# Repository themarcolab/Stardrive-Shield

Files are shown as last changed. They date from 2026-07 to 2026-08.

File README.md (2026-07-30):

# STARDRIVE SHIELD

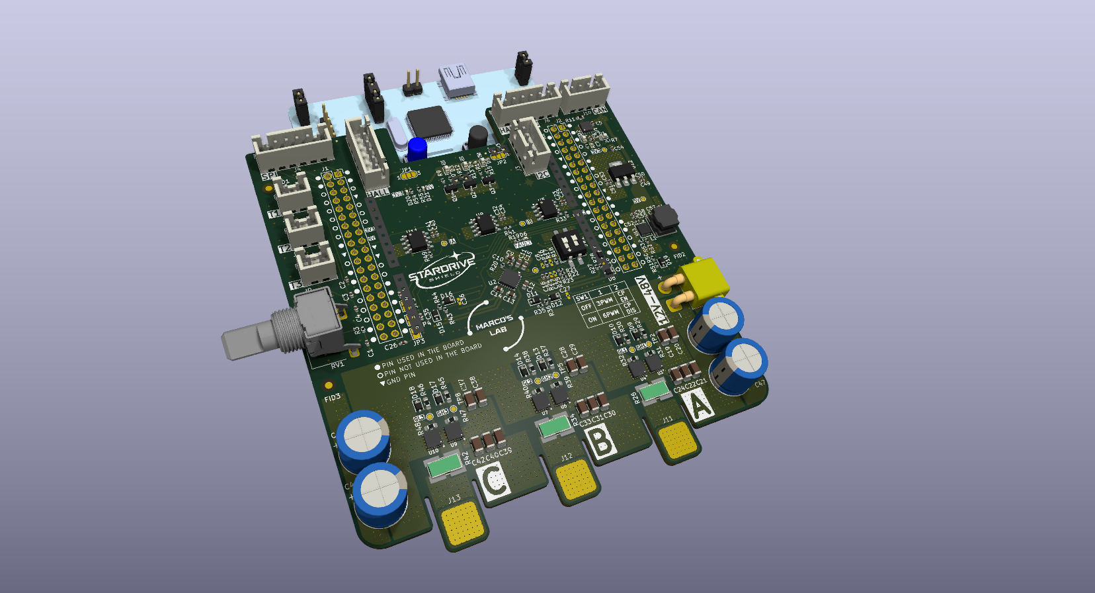
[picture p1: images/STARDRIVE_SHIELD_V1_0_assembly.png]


## Introduction
This project has been born because I have been trying to develop an ESC (hardware and firmware) on my own. 
While the most challenging part has been the firmware (being myself a hardware guy), the most frustrating part has been not finding a flexible hardware platform to develop upon.

So I designed one: **STARDRIVE SHIELD**

## Description 
This is a project with the goal of creating a NUCLEO-64 compatible shield to be used as a flexible platform to develop and test ESC firmware, but also for educational purposes. To do so, I included as many features as possible. These features are not mandatory, but they can be implemented (or not) in the firmware (e.g. SPI, I2C, CAN, HALL) or configured through the hardware interface (e.g. overcurrent protection, 6 or 3 PWM). In this way, the STARDRIVE SHIELD grants flexibility to the developer and it is adapt to various needs.

## Features
The **STARDRIVE SHIELD** is built around the [STDRIVE101](https://www.st.com/en/power-management/stdrive101.html)  gate driver and implementing [BSZ099N06LS5](https://www.infineon.com/part/BSZ099N06LS5) MOSFETs.
It presents 3 in-line shunt resistors and 3 relative [INA240A2](https://www.ti.com/lit/ds/symlink/ina240.pdf?ts=1785176124311&ref_url=https%253A%252F%252Fwww.google.com%252F) current sense amplifiers.

With **STARDRIVE SHIELD** you can implement from 6 step to FOC motor control algorithms.

I designed it to be compatible with Nucleo-G474 and Nucleo-F446. Compatibility with other boards has to be verified. 

### Electrical Characteristics
+ Inprut Voltage V<sub>in</sub> = 12 - 48 V
+ Maximum DC current I<sub>dc,max</sub> = 20 A

### Hardware Characteristiscs
+ Three phase gate driver [STDRIVE101](https://www.st.com/en/power-management/stdrive101.html)
  + Configurable 3PWM or 6PWM through the DIP switch
  + Overcurrent protection can be enabled or disabled through the DIP switch.
  + V<sub>ds</sub> protection configurable with resistor divider (disabled by default)
+ [BSZ099N06LS5](https://www.infineon.com/part/BSZ099N06LS5) MOSFETs
+ 3 in-line shunt resistors (1mOhm) with relative 3 INA240A2 Current Sensors
+ JST connectors to implement:
  + I2C (e.g. for magnetic encoder such as [AS5046](https://mm.digikey.com/Volume0/opasdata/d220001/medias/docus/1138/AS5046.pdf))
  + SPI (e.g. for magnetic encoder such as [AS5047P](https://look.ams-osram.com/m/d05ee39221f9857/original/AS5047P-DS000324.pdf))
  + CAN
  + HALL sensors (some BLDC motors have embedded Hall sensors)
  + 3 NTC temperature sensors
+ 10k Potentiometer to use as throttle signal (or whatever you want)
+ 3 GPIO driven LEDs (1 Red, 1 Blue, 1 Green)
+ 1 FAULT LED (RED)
+ CAN RX and TX LEDs
+ Power Good LEDs

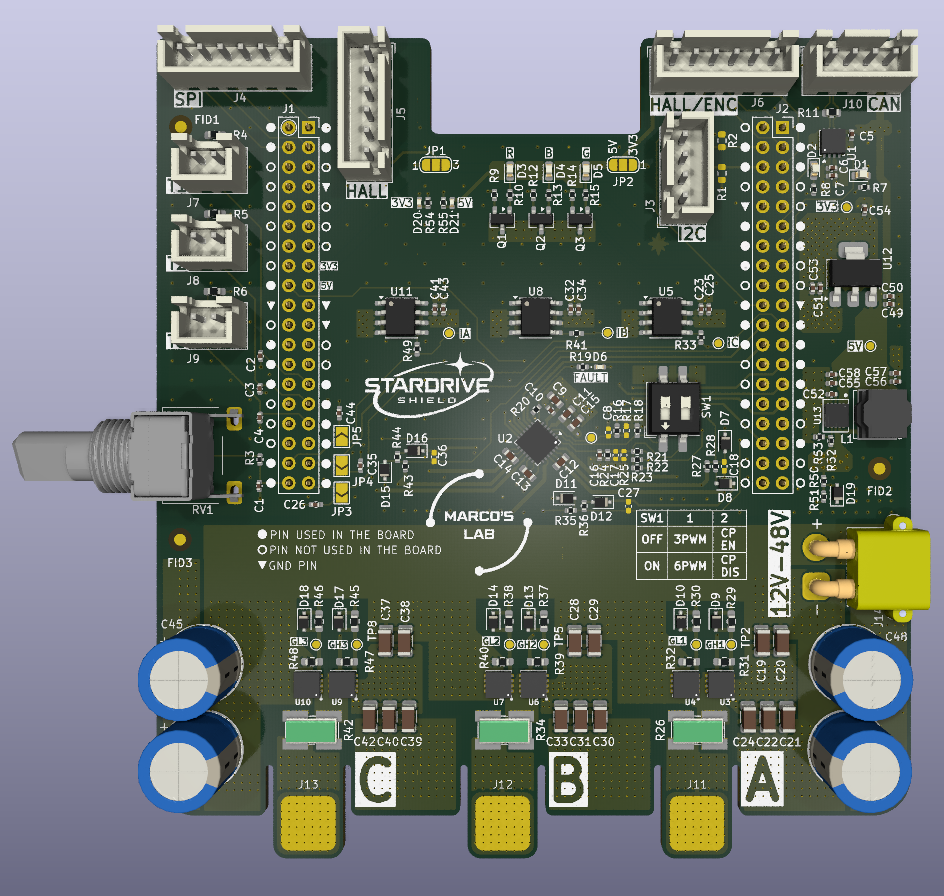
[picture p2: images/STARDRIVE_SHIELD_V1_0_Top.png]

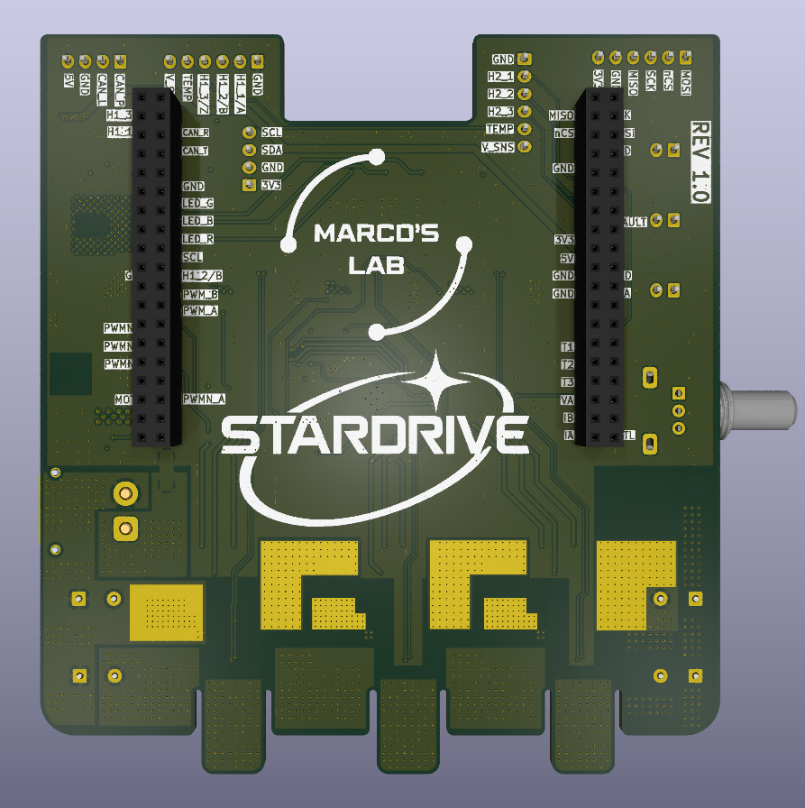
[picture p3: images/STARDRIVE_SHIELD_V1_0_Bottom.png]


## Inspirations
For this project I took inspiration from the [VESC Project](https://vesc-project.com/) and [EVALSTDRIVE101](https://www.st.com/en/evaluation-tools/evalstdrive101.html#cad-resources)

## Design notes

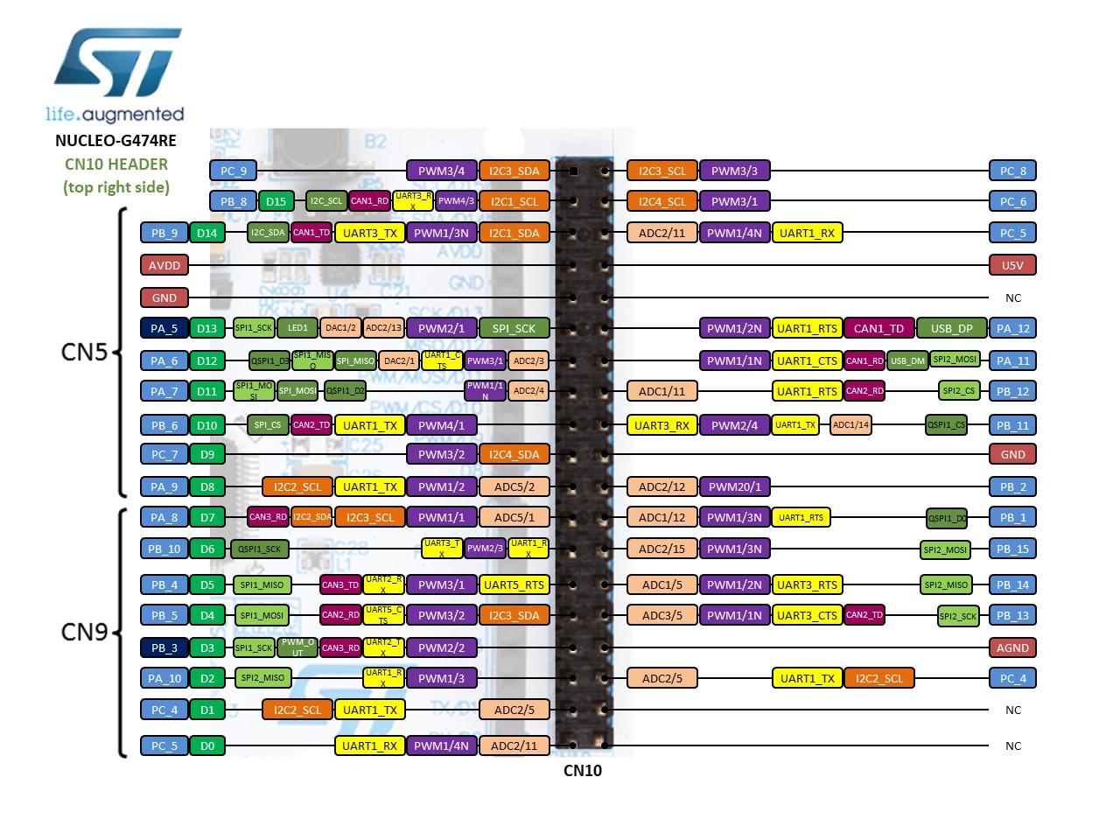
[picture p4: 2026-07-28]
images/nucleo_g474re_2020_9_10_morpho_right.jpg

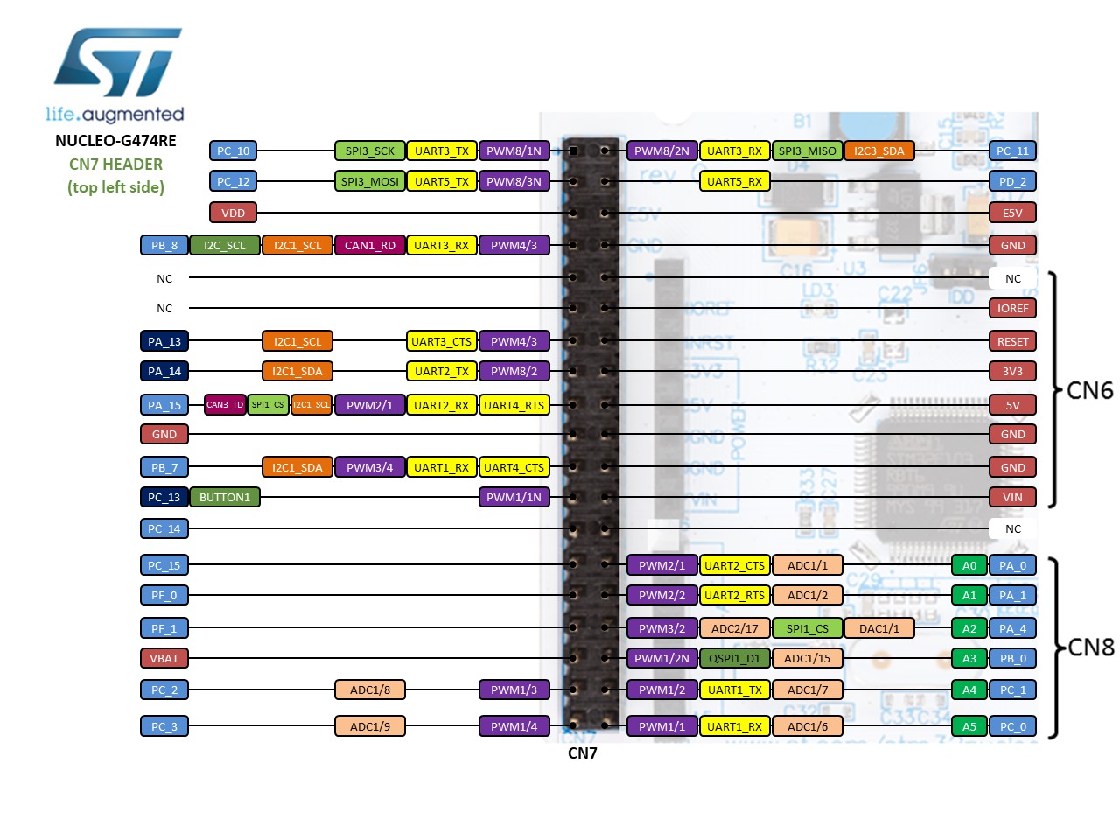
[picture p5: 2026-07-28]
images/nucleo_g474re_2020_9_10_morpho_left.jpg

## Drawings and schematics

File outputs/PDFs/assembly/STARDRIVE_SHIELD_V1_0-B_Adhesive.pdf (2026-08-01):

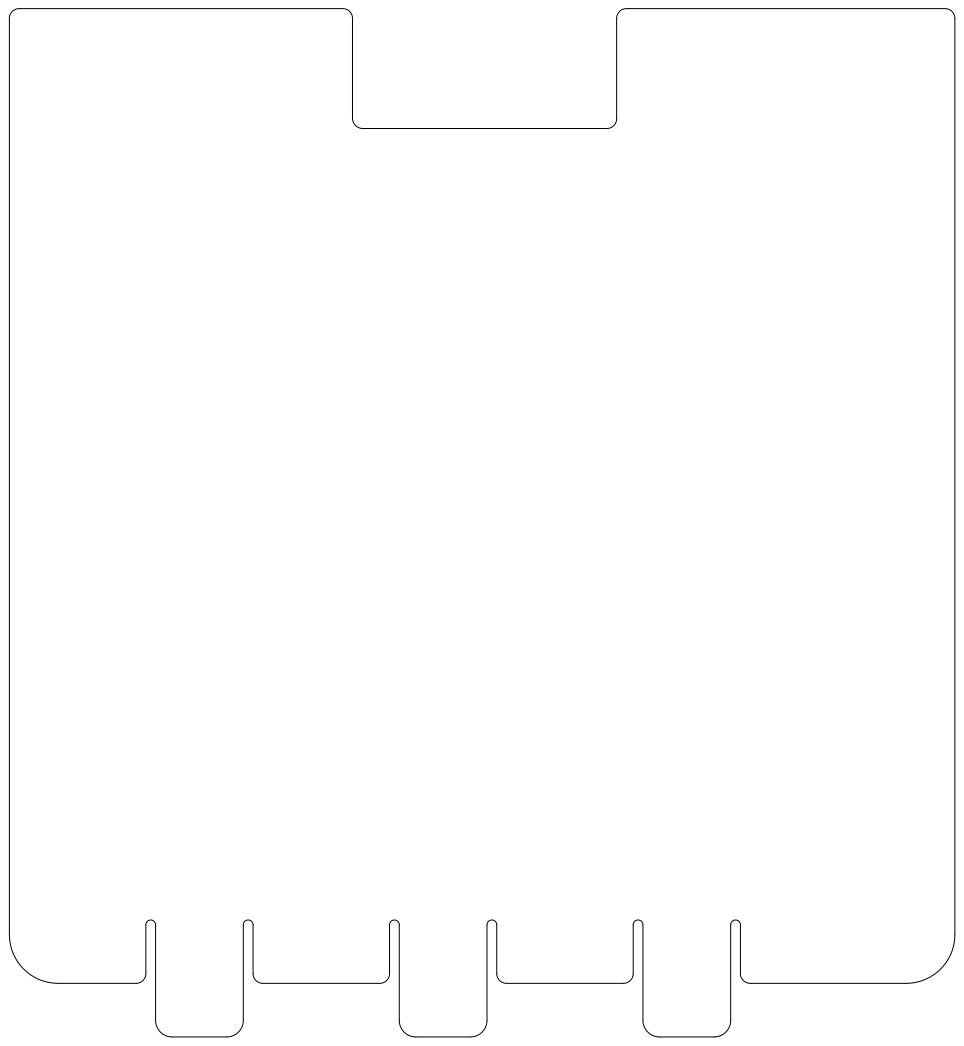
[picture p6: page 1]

Size: A4 Project: STARDRIVE SHIELD V1

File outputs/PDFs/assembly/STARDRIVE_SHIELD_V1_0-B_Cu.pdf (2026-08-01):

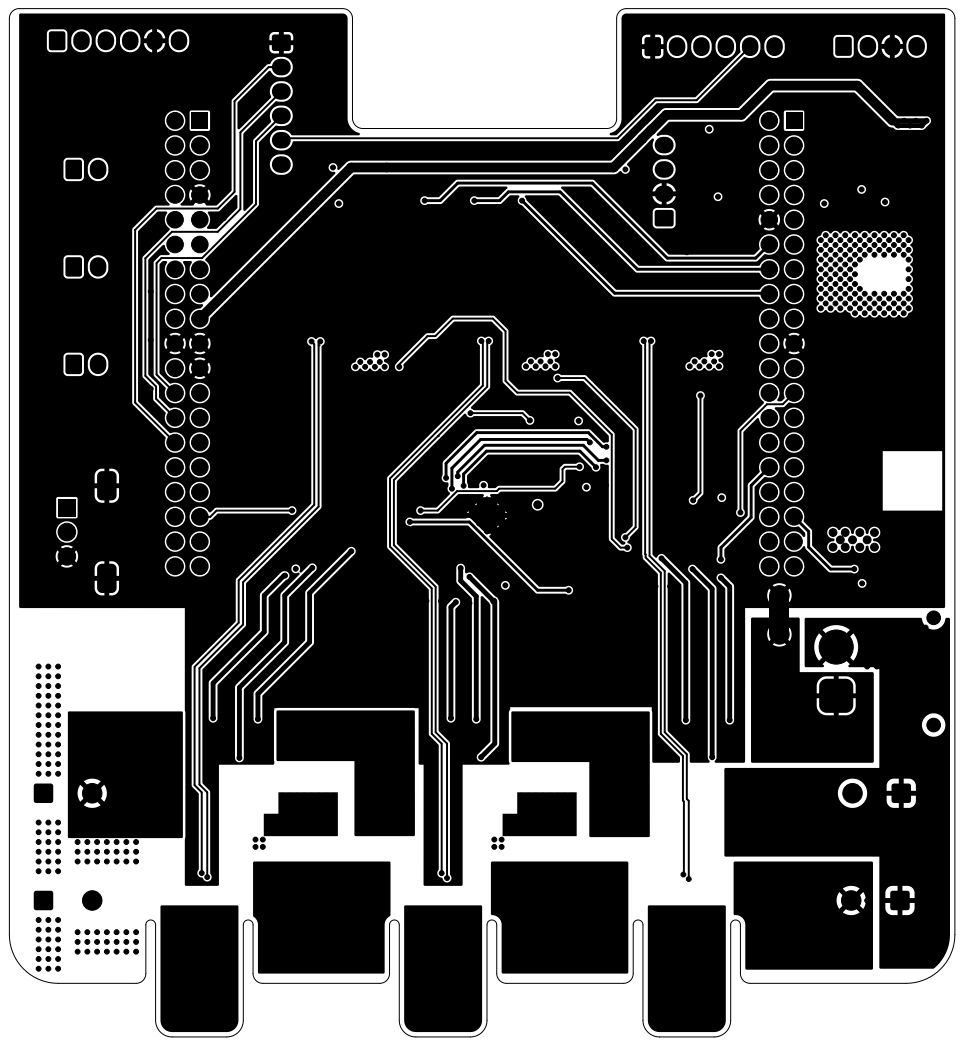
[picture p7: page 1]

Size: A4 Project: STARDRIVE SHIELD V1

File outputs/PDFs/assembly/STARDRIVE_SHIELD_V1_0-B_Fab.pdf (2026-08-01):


Size: A4 Project: STARDRIVE SHIELD V1

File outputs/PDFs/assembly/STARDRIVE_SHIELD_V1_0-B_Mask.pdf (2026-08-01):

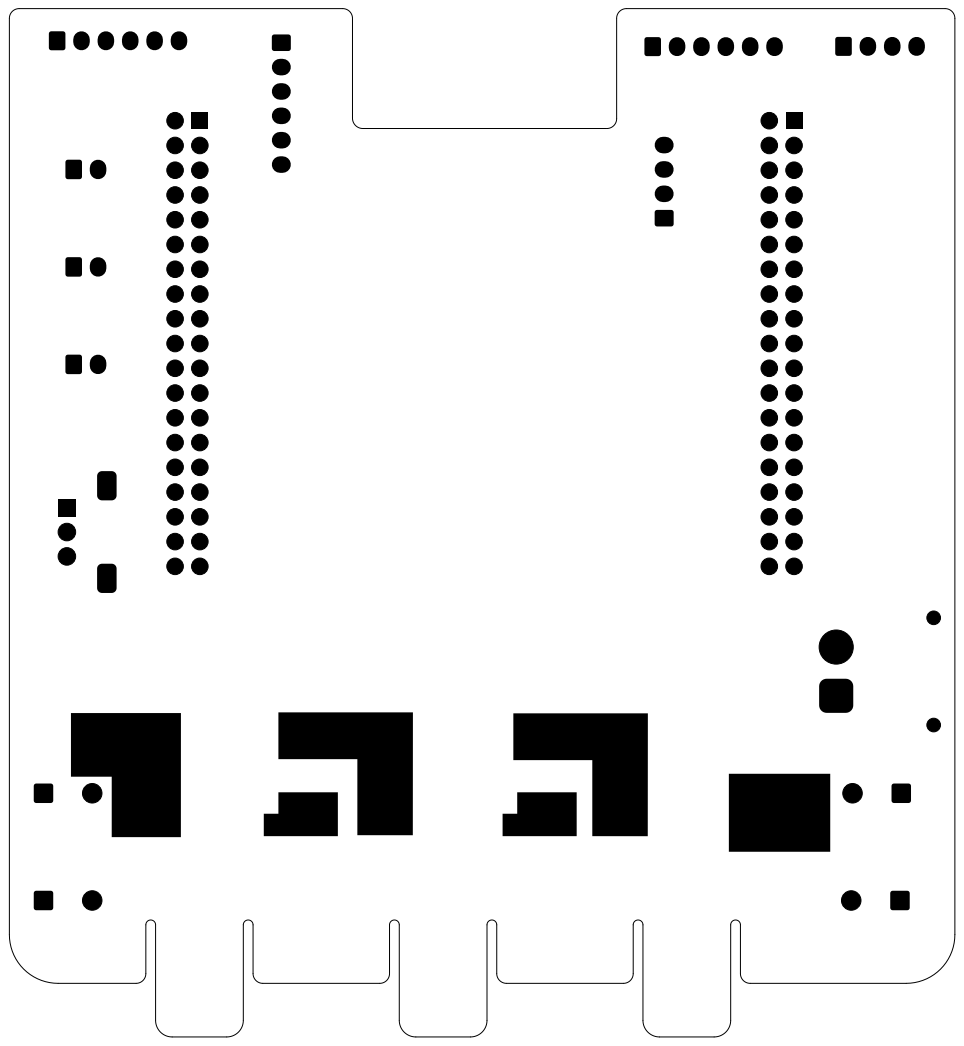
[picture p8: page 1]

Size: A4 Project: STARDRIVE SHIELD V1

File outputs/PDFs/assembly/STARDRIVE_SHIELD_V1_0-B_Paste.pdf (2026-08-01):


Size: A4 Project: STARDRIVE SHIELD V1

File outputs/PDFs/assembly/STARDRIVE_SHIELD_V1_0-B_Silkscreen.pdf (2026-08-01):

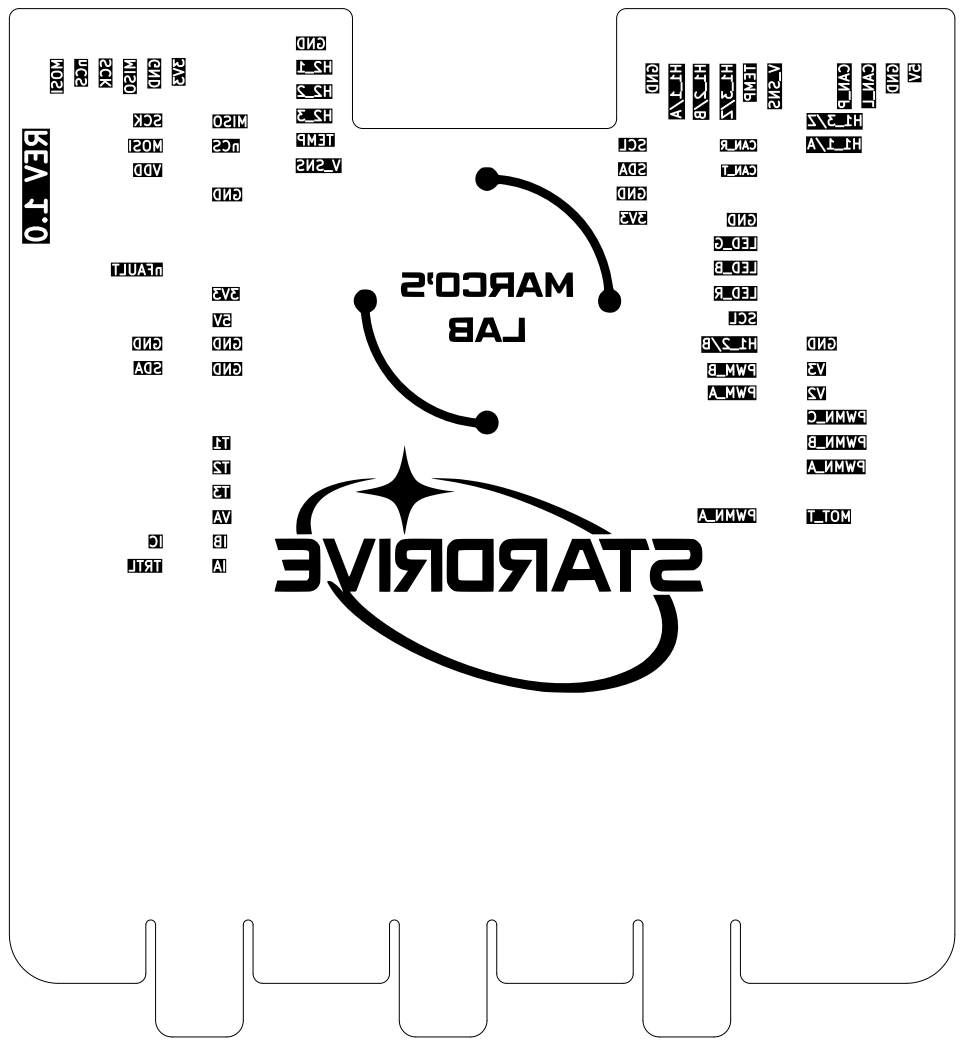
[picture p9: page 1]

Size: A4 Project: STARDRIVE SHIELD V1

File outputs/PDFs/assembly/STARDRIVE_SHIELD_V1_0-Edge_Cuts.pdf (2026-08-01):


Size: A4 Project: STARDRIVE SHIELD V1

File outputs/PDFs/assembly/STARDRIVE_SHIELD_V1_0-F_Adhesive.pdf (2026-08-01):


Size: A4 Project: STARDRIVE SHIELD V1

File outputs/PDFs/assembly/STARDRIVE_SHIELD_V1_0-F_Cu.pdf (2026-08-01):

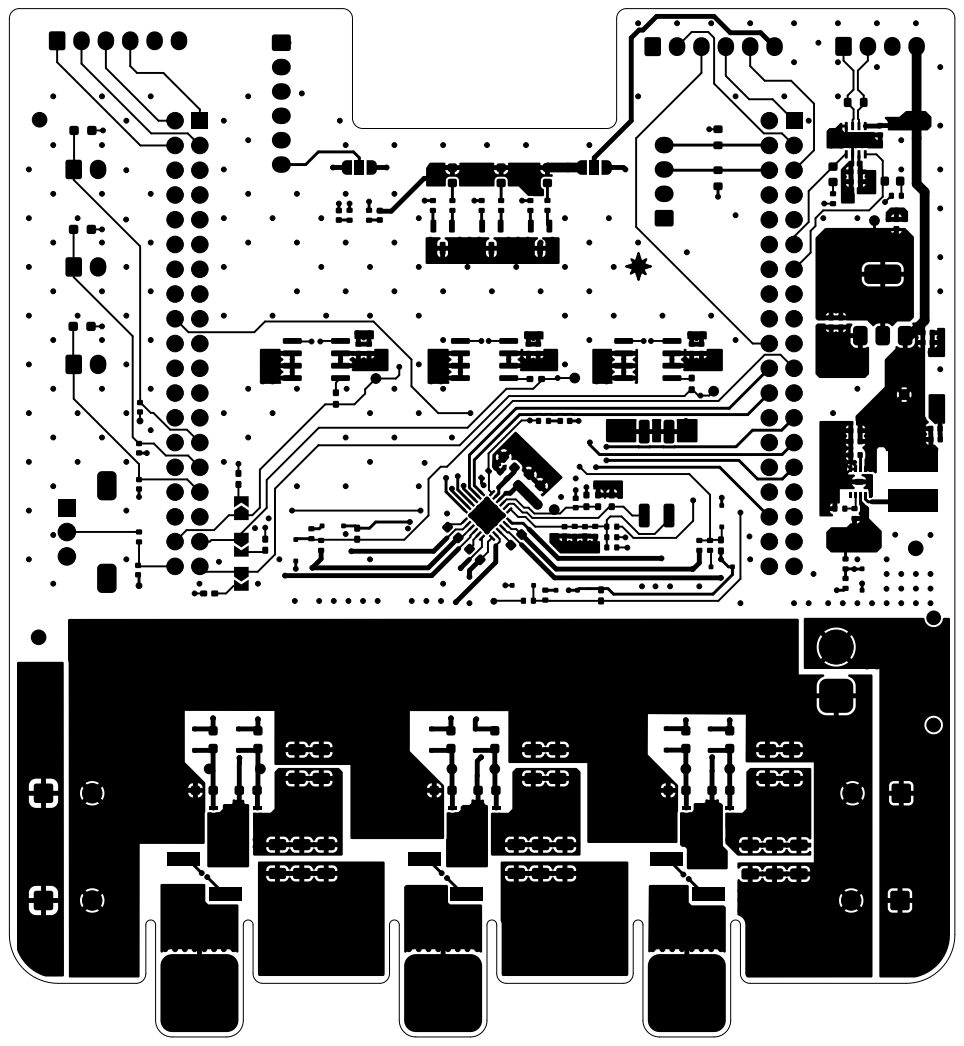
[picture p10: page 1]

Size: A4 Project: STARDRIVE SHIELD V1

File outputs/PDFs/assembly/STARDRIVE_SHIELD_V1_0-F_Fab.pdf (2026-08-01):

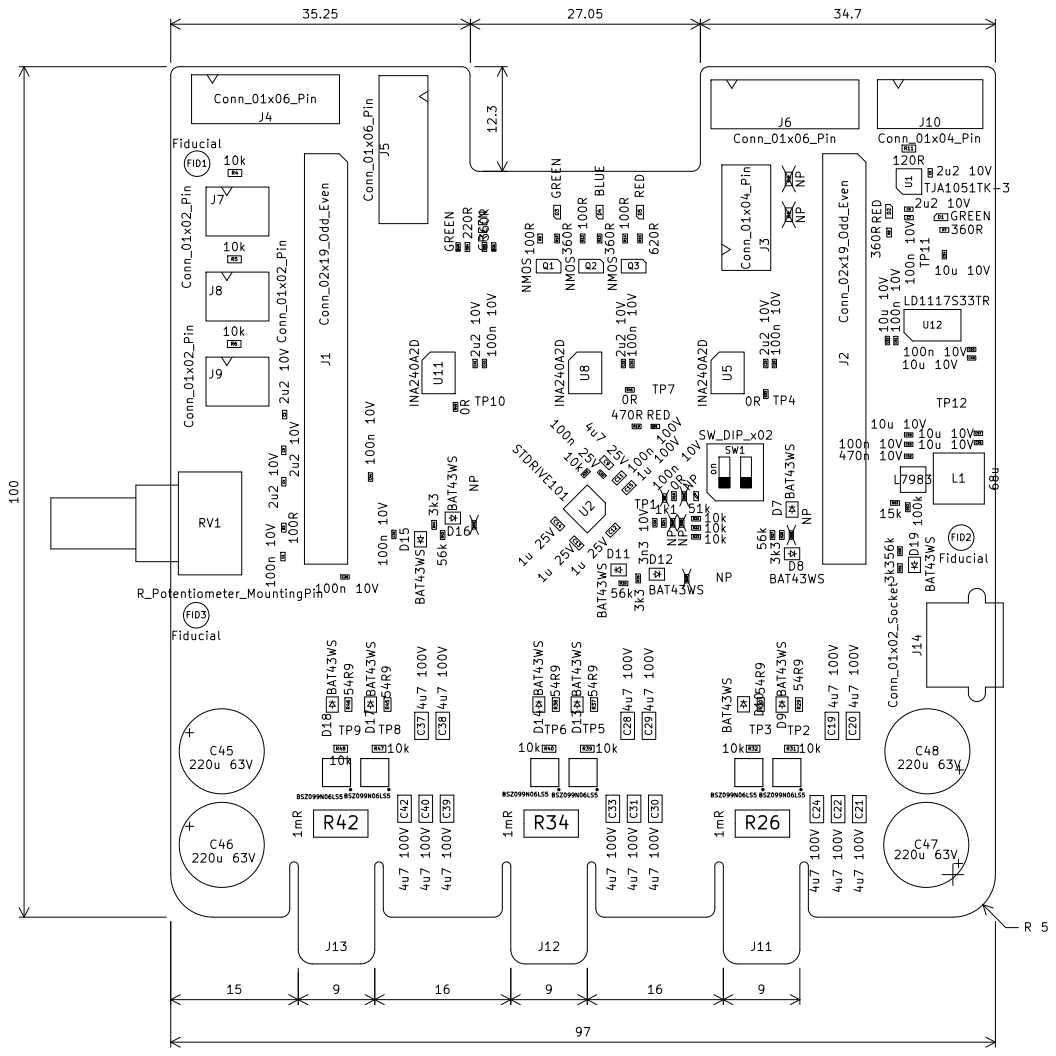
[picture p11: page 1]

Size: A4 Project: STARDRIVE SHIELD V1

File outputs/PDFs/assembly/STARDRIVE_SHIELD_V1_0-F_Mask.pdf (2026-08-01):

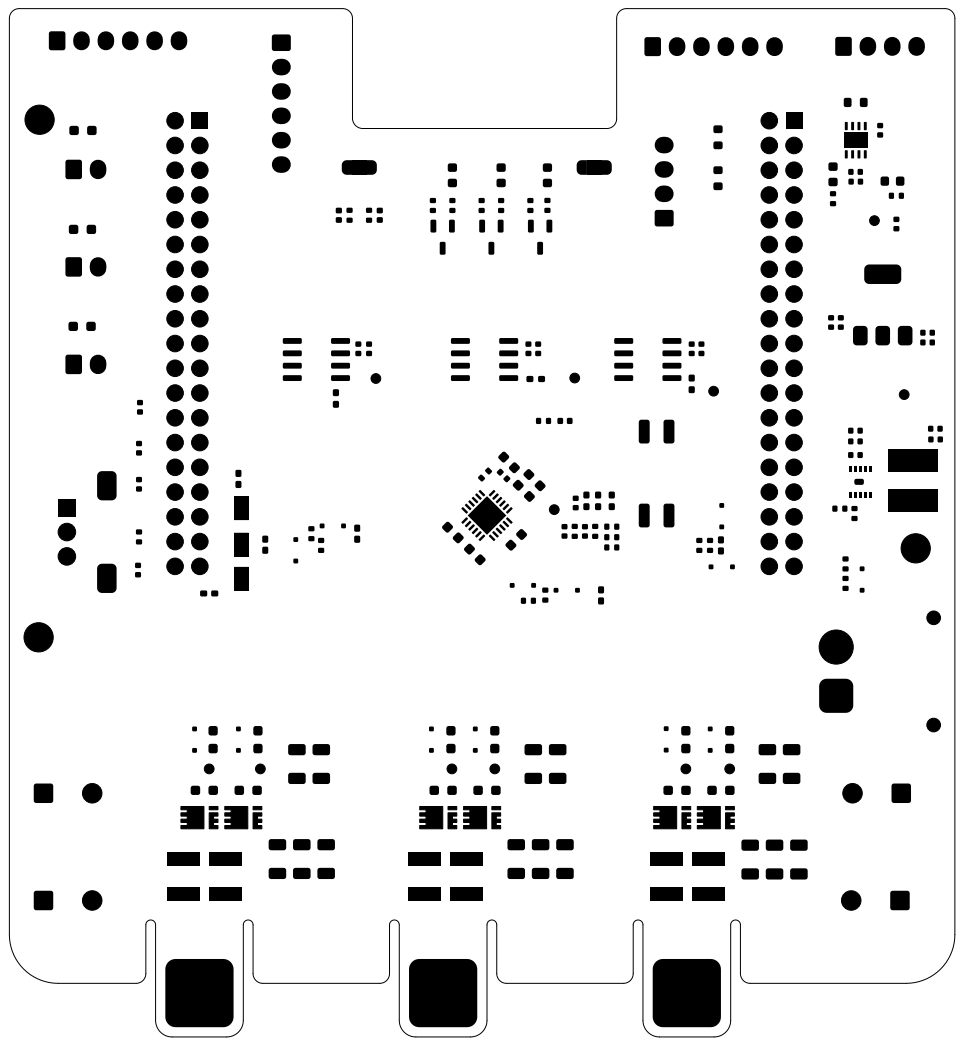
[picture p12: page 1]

Size: A4 Project: STARDRIVE SHIELD V1

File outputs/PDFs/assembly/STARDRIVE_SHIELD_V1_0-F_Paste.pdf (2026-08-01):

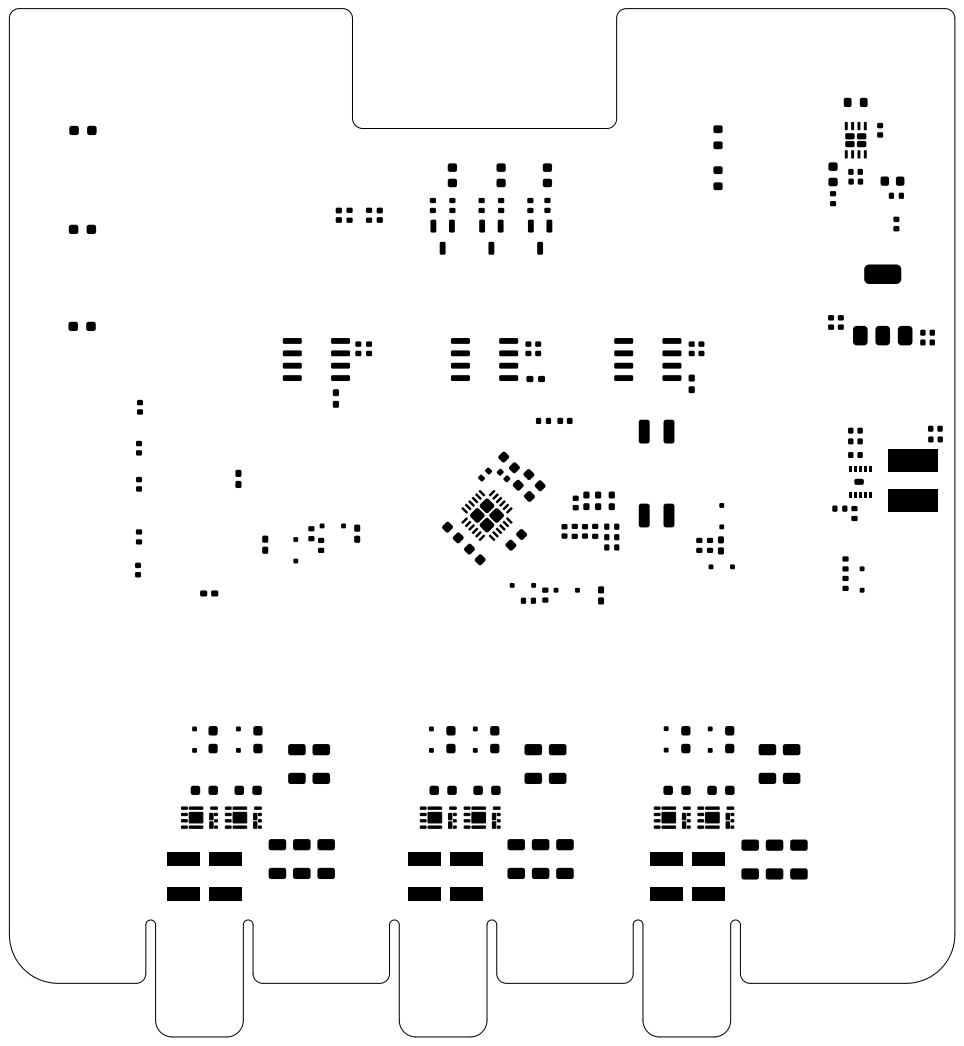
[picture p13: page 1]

Size: A4 Project: STARDRIVE SHIELD V1

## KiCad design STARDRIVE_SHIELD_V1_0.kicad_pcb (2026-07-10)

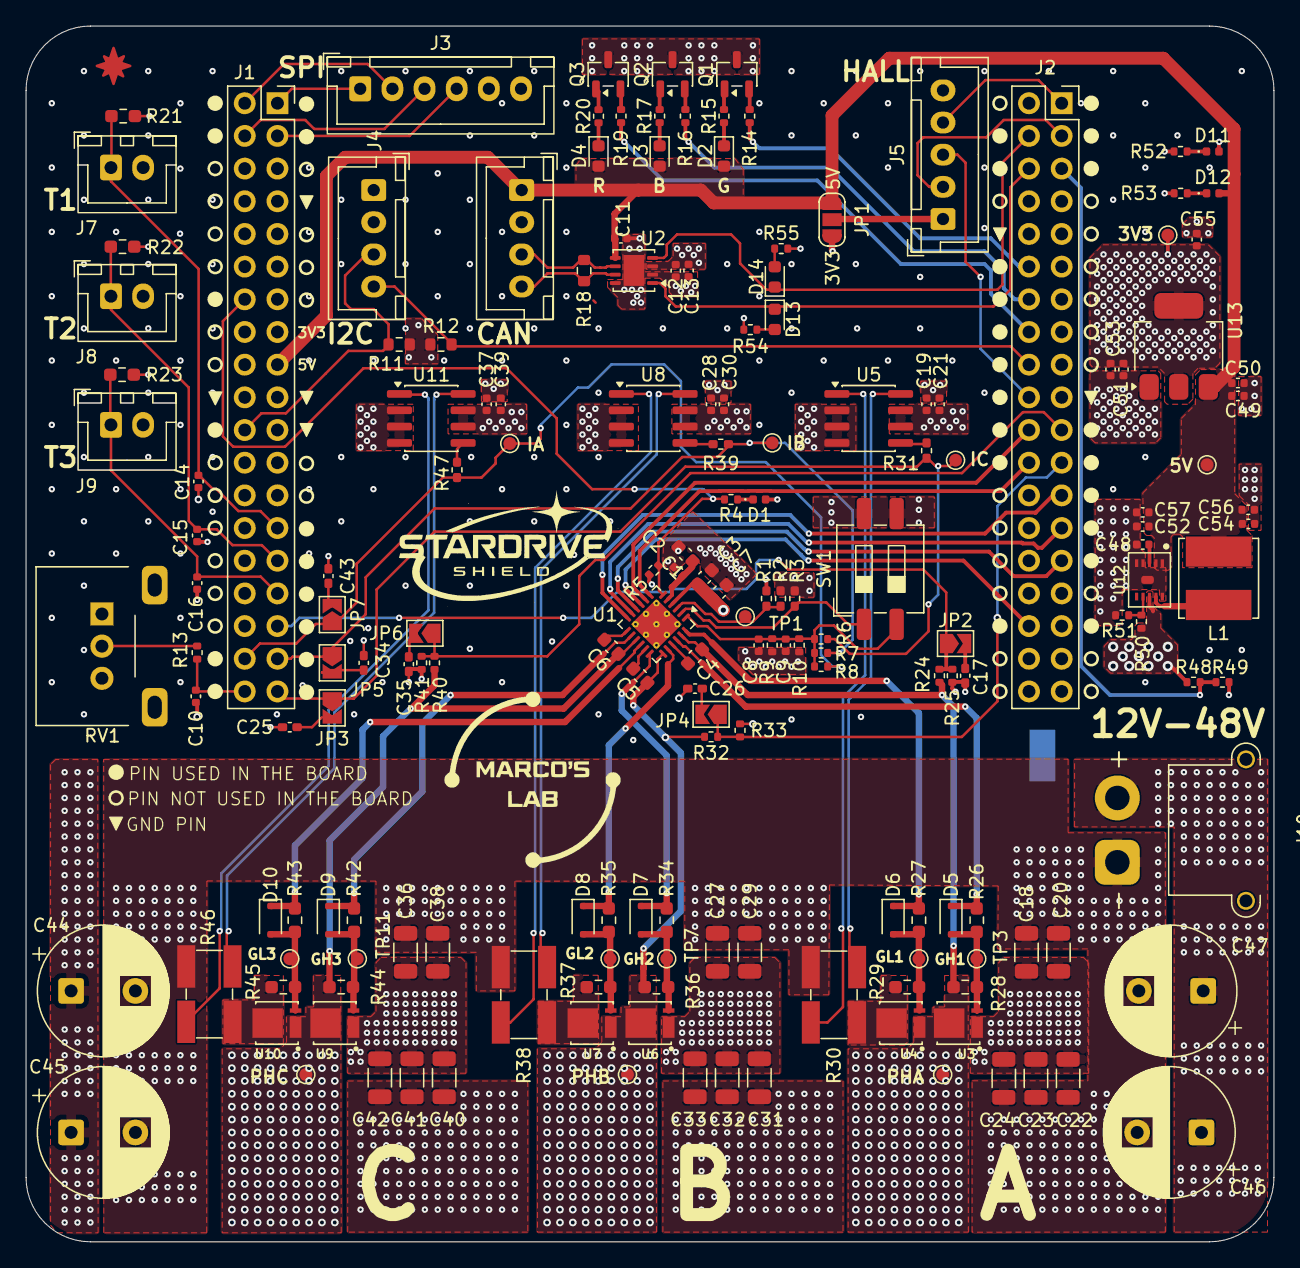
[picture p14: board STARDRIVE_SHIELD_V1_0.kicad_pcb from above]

Board: 4 copper layers, 97.0 x 94.5 mm, 178 parts (1 on the bottom side), 98 nets.

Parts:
C1: 4u7 25V; C_0603_1608Metric
C2: 100n 25V; C_0402_1005Metric
C3: 100n 100V; C_0603_1608Metric
C4, C5, C6: 1u 25V; C_0603_1608Metric
C7: 1u 100V; C_0603_1608Metric
C8: 3n3 10V; C_0402_1005Metric
C9: NP; C_0402_1005Metric
C10, C13, C21, C30, C39, C50, C51, C52: 100n 10V; C_0402_1005Metric
C11, C12, C14, C15, C16, C19, C28, C37: 2u2 10V; C_0402_1005Metric
C17, C25, C26, C34, C35, C43: 100n 10V; C_0402_1005Metric_Pad0.74x0.62mm_HandSolder
C18, C20, C22, C23, C24, C27, C29, C31, C32, C33, C36, C38, C40, C41, C42: 4u7 100V; C_1206_3216Metric
C44, C45, C46, C47: 220u 63V; CP_Radial_D10.0mm_P5.00mm
C48: 470n 10V; C_0402_1005Metric
C49, C53, C54, C55, C56, C57: 10u 10V; C_0402_1005Metric
D1: RED; LED_0402_1005Metric
D2, D14: GREEN; LED_0603_1608Metric
D3: BLUE; LED_0603_1608Metric
D4, D13: RED; LED_0603_1608Metric
D5, D6, D7, D8, D9, D10: BAT43WS; D_SOD-323F
D11, D12: GREEN; LED_0402_1005Metric
J1, J2: Conn_02x19_Odd_Even; PinSocket_2x19_P2.54mm_Vertical
J3: Conn_01x06_Pin; JST_XH_B6B-XH-A_1x06_P2.50mm_Vertical
J4, J6: Conn_01x04_Pin; JST_XH_B4B-XH-A_1x04_P2.50mm_Vertical
J5: Conn_01x05_Pin; JST_XH_B5B-XH-A_1x05_P2.50mm_Vertical
J7, J8, J9: Conn_01x02_Pin; JST_XH_B2B-XH-A_1x02_P2.50mm_Vertical
J10: XT30PW-M; AMASS_XT30PW-M_1x02_P2.50mm_Horizontal
JP1: SolderJumper_3_Open; SolderJumper-3_P1.3mm_Open_RoundedPad1.0x1.5mm_NumberLabels
JP2, JP3, JP4, JP5, JP6, JP7: SolderJumper; SolderJumper-2_P1.3mm_Open_TrianglePad1.0x1.5mm
L1: 68u; L_Bourns_SRN6045TA
NT1: NetTie_2; NetTie-2_SMD_Pad2.0mm
Q1, Q2, Q3: NMOS; SOT-23-3
R1, R31, R39, R47: 0R; R_0402_1005Metric_Pad0.72x0.64mm_HandSolder
R2: NP; R_0402_1005Metric_Pad0.72x0.64mm_HandSolder
R3: 51k; R_0402_1005Metric_Pad0.72x0.64mm_HandSolder
R4: 470R; R_0402_1005Metric
R5, R6, R7, R8: 10k; R_0402_1005Metric
R9: 1k1; R_0402_1005Metric
R10: NP; R_0402_1005Metric
R11, R12: NP; R_0603_1608Metric
R13, R14, R16, R19: 100R; R_0402_1005Metric
R15, R17, R53, R54, R55: 360R; R_0402_1005Metric
R18: 120R; R_0603_1608Metric
R20: 620R; R_0402_1005Metric
R21, R22, R23, R28, R29, R36, R37, R44, R45: 10k; R_0603_1608Metric_Pad0.98x0.95mm_HandSolder
R24, R32, R40, R48: 56k; R_0402_1005Metric
R25, R33, R41, R49: 3k3; R_0402_1005Metric
R26, R27, R34, R35, R42, R43: 54R9; R_0603_1608Metric_Pad0.98x0.95mm_HandSolder
R30, R38, R46: 1mR; R_Shunt_Ohmite_LVK25
R50: 100k; R_0402_1005Metric
R51: 15k; R_0402_1005Metric
R52: 220R; R_0402_1005Metric
RV1: R_Potentiometer; Potentiometer_Alps_RK09L_Single_Horizontal
SW1: SW_DIP_x02; SW_DIP_SPSTx02_Slide_6.7x6.64mm_W8.61mm_P2.54mm_LowProfile
TP1, TP2, TP3, TP4, TP5, TP6, TP7, TP8, TP9, TP10, TP11, TP12, TP13, TP14, TP15: TestPoint; TestPoint_Pad_D1.0mm
U1: STDRIVE101; QFN-24-1EP_4x4mm_P0.5mm_EP2.8x2.8mm_ThermalVias
U2: TJA1051TK-3; HVSON-8-1EP_3x3mm_P0.65mm_EP1.6x2.4mm
U3, U4, U6, U7, U9, U10: BSZ099N06LS5; PG-TSDSON-8
U5, U8, U11: INA240A2D; SOIC-8_3.9x4.9mm_P1.27mm
U12: L7983; DFN-10-1EP_3mmX3mm_P0.5mm_ExposedPad_0.62x0.98mm
U13: LD1117S33TR; SOT-223-3_TabPin2

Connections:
+3V3: C12.1, C13.1, C19.1, C21.1, C28.1, C30.1, C37.1, C39.1, C51.1, C53.1, C55.1, J1.15, J3.6, J4.1, J7.2, J8.2, J9.2, R11.1, R12.1, RV1.1, U2.3 (VCC), U5.6 (V+), U5.7 (REF1), U8.6 (V+), U8.7 (REF1), U11.6 (V+), U11.7 (REF1), U13.2 (VO)
+5V: C11.1, C49.1, C50.1, C52.1, C54.1, C56.1, C57.1, D2.2 (A), D3.2 (A), D4.2 (A), D12.2 (A), J1.17, J6.1, JP1.3 (B), L1.2, TP15.1 (1_1), U2.5 (VIO), U12.1 (VOUT/FB), U12.2 (VBIAS), U13.3 (VI)
+12V: C1.1, C2.1, U1.5 (REG12)
/Connectors/ADC1.CURR1: J1.37, JP3.1 (A), R6.1, R31.1, TP5.1 (1_1)
/Connectors/ADC1.CURR2: J1.35, JP5.1 (A), R7.1, R39.1, TP9.1 (1_1)
/Connectors/ADC1.CURR3: J1.36, JP7.1 (A), R8.1, R47.1, TP13.1 (1_1)
/Connectors/ADC1.TEMP1: C14.1, J1.27, J7.1, R21.2
/Connectors/ADC1.TEMP2: C15.1, J1.29, J8.1, R22.2
/Connectors/ADC1.TEMP3: C16.1, J1.31, J9.1, R23.2
/Connectors/ADC1.THROTTLE: C10.1, J1.38, R13.1
/Connectors/ADC1.VOLTAGE1: J1.33, JP2.1 (A), R24.2, R25.1
/Connectors/ADC1.VOLTAGE2: J2.23, JP4.1 (A), R32.2, R33.1
/Connectors/ADC1.VOLTAGE3: J2.21, JP6.1 (A), R40.2, R41.1
/Connectors/ADC1.V_BUS: J2.5, R48.2, R49.1
/Connectors/CAN1.CAN+: J6.4, R18.1, U2.7 (CANH)
/Connectors/CAN1.CAN-: J6.3, R18.2, U2.6 (CANL)
/Connectors/CAN1.RX: D14.1 (K), J2.4, U2.4 (RXD)
/Connectors/CAN1.TX: D13.1 (K), J2.6, U2.1 (TXD)
/Connectors/I2C1.SCL: J2.18, J4.4, R12.2
/Connectors/I2C1.SDA: J1.22, J4.3, R11.2
/Connectors/LEDS.BLUE: J2.14, R16.1
/Connectors/LEDS.GREEN: J2.12, R14.1
/Connectors/LEDS.RED: J2.16, R19.1
/Connectors/SPI3.MISO: J1.1, J3.1
/Connectors/SPI3.MOSI: J1.4, J3.3
/Connectors/SPI3.SCK: J1.2, J3.2
/Connectors/SPI3.nCS: J1.3, J3.4
/Connectors/TIM1.PWM1: J2.24, U1.7 (INH1/IN1)
/Connectors/TIM1.PWM2: J2.22, U1.8 (INH2/IN2)
/Connectors/TIM1.PWM3: J2.34, U1.9 (INH3/IN3)
/Connectors/TIM1.PWMN1: J2.29, U1.10 (INL1/EN1)
/Connectors/TIM1.PWMN2: J2.27, U1.11 (INL2/EN2)
/Connectors/TIM1.PWMN3: J2.25, U1.12 (INL3/EN3)
/Connectors/TIM3.HALL1: J2.3, J5.2
/Connectors/TIM3.HALL2: J2.20, J5.3
/Connectors/TIM3.HALL3: J2.1, J5.4
/Connectors/nFAULT: J1.14, R4.2, R5.2, U1.6 (nFAULT)
/Interfaces/+V_HALL: J5.1, JP1.2 (C)
/Inverter/CP: C8.1, C9.1, R6.2, R7.2, R8.2, R9.2, R10.2, SW1.2, U1.1 (CP)
/Inverter/DT/MODE: R3.1, SW1.1, U1.2 (DT/MODE)
/Inverter/Half-Bridge1/GH: D5.1, R26.1, U1.22 (GHS1)
/Inverter/Half-Bridge1/GL: D6.1, R27.1, U1.24 (GLS1)
/Inverter/Half-Bridge1/PH: C4.2, R24.1, R28.1, TP2.1 (1_1), U1.23 (OUT1), U3.3, U4.1
/Inverter/Half-Bridge1/R_SNS+: R30.2, U5.8 (+)
/Inverter/Half-Bridge1/R_SNS-: R30.3, U5.1 (-)
/Inverter/Half-Bridge2/GH: D7.1, R34.1, U1.18 (GHS2)
/Inverter/Half-Bridge2/GL: D8.1, R35.1, U1.20 (GLS2)
/Inverter/Half-Bridge2/PH: C5.2, R32.1, R36.1, TP6.1 (1_1), U1.19 (OUT2), U6.3, U7.1
/Inverter/Half-Bridge2/R_SNS+: R38.2, U8.8 (+)
/Inverter/Half-Bridge2/R_SNS-: R38.3, U8.1 (-)
/Inverter/Half-Bridge3/GH: D9.1, R42.1, U1.14 (GHS3)
/Inverter/Half-Bridge3/GL: D10.1, R43.1, U1.16 (GLS3)
/Inverter/Half-Bridge3/PH: C6.2, R40.1, R44.1, TP10.1 (1_1), U1.15 (OUT3), U9.3, U10.1
/Inverter/Half-Bridge3/R_SNS+: R46.2, U11.8 (+)
/Inverter/Half-Bridge3/R_SNS-: R46.3, U11.1 (-)
/Inverter/SCREF: R1.2, R2.1, TP1.1 (1_1), U1.3 (SCREF)
GND: C1.2, C2.2, C3.2, C7.2, C8.2, C9.2, C10.2, C11.2, C12.2, C13.2, C14.2, C15.2, C16.2, C17.2, C19.2, C21.2, C25.2, C26.2, C28.2, C30.2, C34.2, C35.2, C37.2, C39.2, C43.2, C48.2, C49.2, C50.2, C51.2, C52.2, C53.2, C54.2, C55.2, C56.2, C57.2, D1.2 (A), D11.2 (A), J1.7, J1.19, J1.20, J1.21, J2.10, J2.19, J3.5, J4.2, J5.5, J6.2, JP1.1 (A), NT1.1, Q1.3 (S), Q2.3 (S), Q3.3 (S), R1.1, R2.2, R3.2, R5.1, R9.1, R10.1, R21.1, R22.1, R23.1, R25.2, R33.2, R41.2, R49.2, R51.2, R52.2, R53.2, R54.1, R55.1, RV1.3, RV1.MP (MountPin), SW1.3, SW1.4, TP14.1 (1_1), U1.25 (GND/EPAD), U2.2 (GND), U2.8 (S), U2.9 (GND), U5.2 (GND), U5.3 (REF2), U5.4 (GND), U8.2 (GND), U8.3 (REF2), U8.4 (GND), U11.2 (GND), U11.3 (REF2), U11.4 (GND), U12.4 (FSW), U12.5 (LNM/nLCM), U12.10 (GND), U12.11 (EPAD), U13.1 (GND)
unnamed: D1.1 (K), R4.1
unnamed: D2.1 (K), R15.1
unnamed: D3.1 (K), R17.1
unnamed: D4.1 (K), R20.1
unnamed: D5.2, R26.2, R28.2, TP3.1 (1_1), U3.2
unnamed: D6.2, R27.2, R29.2, TP4.1 (1_1), U4.2
unnamed: D7.2, R34.2, R36.2, TP7.1 (1_1), U6.2
unnamed: D8.2, R35.2, R37.2, TP8.1 (1_1), U7.2
unnamed: D9.2, R42.2, R44.2, TP11.1 (1_1), U9.2
unnamed: D10.2, R43.2, R45.2, TP12.1 (1_1), U10.2
unnamed: D11.1 (K), R52.1
unnamed: D12.1 (K), R53.1
unnamed: D13.2 (A), R54.2
unnamed: D14.2 (A), R55.2
unnamed: C17.1, JP2.2 (B)
unnamed: C25.1, JP3.2 (B)
unnamed: C26.1, JP4.2 (B)
unnamed: C34.1, JP5.2 (B)
unnamed: C35.1, JP6.2 (B)
unnamed: C43.1, JP7.2 (B)
unnamed: Q1.1 (D), R15.2
unnamed: Q1.2 (G), R14.2
unnamed: Q2.1 (D), R17.2
unnamed: Q2.2 (G), R16.2
unnamed: Q3.1 (D), R20.2
unnamed: Q3.2 (G), R19.2
unnamed: R13.2, RV1.2
unnamed: R29.1, R30.1, U4.3
unnamed: R31.2, U5.5
unnamed: R37.1, R38.1, U7.3
unnamed: R39.2, U8.5
unnamed: R45.1, R46.1, U10.3
unnamed: R47.2, U11.5
unnamed: C4.1, U1.21 (BOOT1)
unnamed: C5.1, U1.17 (BOOT2)
unnamed: C6.1, U1.13 (BOOT3)
unnamed: R50.2, R51.1, U12.7 (EN/UVLO)
unnamed: L1.1, U12.9 (LX)
unnamed: C48.1, U12.3 (VCC)
PGND: C18.2, C20.2, C22.2, C23.2, C24.2, C27.2, C29.2, C31.2, C32.2, C33.2, C36.2, C38.2, C40.2, C41.2, C42.2, C44.2, C45.2, C46.2, C47.2, J10.1, NT1.2, R30.4, R38.4, R46.4
VBUS: C3.1, C7.1, C18.1, C20.1, C22.1, C23.1, C24.1, C27.1, C29.1, C31.1, C32.1, C33.1, C36.1, C38.1, C40.1, C41.1, C42.1, C44.1, C45.1, C46.1, C47.1, J10.2, R48.1, R50.1, U1.4 (VS), U3.1, U6.1, U9.1, U12.8 (VIN)

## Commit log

2026-07-10 First commit: KiCad Project ready to be published
    [Connectors.kicad_sch, Half-Bridge.kicad_sch, Interfaces.kicad_sch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]
2026-07-10 Added GPIO_BEMF and adjusted BEMF circuit
    [Connectors.kicad_sch, Half-Bridge.kicad_sch, Interfaces.kicad_sch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]
2026-07-10 Added clamping Diode to Vbus sense circuit
    [PowerStage.kicad_sch]
2026-07-13 Adjusted grounding on BOT layer. Added Fiducial
    [main.kicad_sch]
2026-07-16 Modified esthetics schematics. Modified bottom thermal openings.
    [Connectors.kicad_sch, Half-Bridge.kicad_sch, Interfaces.kicad_sch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]
2026-07-27 Repositioned components and redefined board edges to fix interference with NUCLEO BOARD buttons
    [Connectors.kicad_sch, Interfaces.kicad_sch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]
2026-07-27 Updated PDF schematic
2026-07-28 Small silkscreen modifications and added images folder
2026-07-28 Assembly render added to images
2026-07-30 M: Changed to IN-LINE SHUNTS m: Added Encoder notation in HALL Connectors
    [Half-Bridge.kicad_sch, Interfaces.kicad_sch, Inverter.kicad_sch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]
2026-08-01 M: Added new connector for HALL sensors. Previous one marked to be used for encoders as well. As consequence also the pinout of MORPHO CONNECTORS has changed as well as the position of connectors and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
    [Connectors.kicad_sch, Half-Bridge.kicad_sch, Interfaces.kicad_sch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]
2026-08-07 M: fixed MPN of R11 from 0402 to 0603 component
    [Half-Bridge.kicad_sch, Interfaces.kicad_sch, PowerStage.kicad_sch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]
